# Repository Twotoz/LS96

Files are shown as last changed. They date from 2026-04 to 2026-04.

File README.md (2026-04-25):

# 1S 2-Inch High-KV Toothpick FPV Quad

A custom ultra-light **1S 2-inch toothpick FPV quad** designed around a specific idea:

> **Use a small, high-KV 2-inch powertrain for extreme responsiveness and punch, but place it on a larger 96 mm frame to gain stability, grip, protection, and a more locked-in flight feel.**



This is not a normal compact 2-inch toothpick, and it is not trying to become a slow, floaty 3-inch cruiser.

It is designed to sit between both concepts:

- **2-inch response**
- **high-KV punch**
- **low prop inertia**
- **larger-frame stability**
- **better component protection**
- **very low AUW**
- **extreme 1S thrust-to-weight**

In short:

> **A 1S 2-inch toothpick with 5-inch attitude.**

---

## Core Concept

Most 2-inch toothpick frames are around **85 mm motor-to-motor**. They are compact, light, and responsive, but can also feel twitchy and nervous at speed.

This frame uses a larger **96 mm wheelbase**, while still staying extremely light. The larger wheelbase gives the quad more mechanical leverage, more stability, better component protection, and a less twitchy feel.

At the same time, the quad still uses:

- high-KV 1002 motors
- 2-inch lightweight bi-blade props
- very low prop inertia
- low AUW
- 1S power

This keeps the quad extremely responsive and punchy.

The design goal is:

```text
2-inch responsiveness
+
high-KV punch
+
96 mm locked-in frame feel
=
responsive, stable, aggressive 1S micro quad
```

---

## Main Specs

| Item | Specification |
|---|---:|
| Class | 1S 2-inch toothpick |
| Frame wheelbase | 96 mm |
| Typical 2-inch frame reference | ~85 mm |
| Frame material | Carbon fiber |
| Frame thickness | 2 mm |
| Frame area | ~1258 mm² |
| Estimated frame weight | ~3.8–4.0 g |
| Motors | 1002 high-KV brushless |
| Planned KV | 25000KV |
| Alternative KV | 22000KV |
| Motor weight | ~2.5 g each including wires |
| Props | Gemfan GF2015 bi-blade |
| Prop size | 2.0 inch |
| Experimental prop size | 2.2 inch low pitch |
| Battery | 1S LiHV, LAVA 580 mAh |
| Estimated dry weight | ~25–26 g |
| Estimated AUW | ~39–40 g |
| Estimated thrust | ~400–412 g total |
| Estimated thrust-to-weight | ~10:1 |

---

## Estimated Weight Breakdown

| Component | Estimated Weight |
|---|---:|
| 2 mm carbon frame | ~3.8–4.0 g |
| 4x 1002 motors, including wires | ~10.0 g |
| Canopy | ~0.55 g |
| Camera | ~1.5 g |
| FC AIO | ~4.0 g |
| Battery connector + wires | ~2.0 g |
| 4x Gemfan GF2015 bi-blade props | ~2.0 g |
| 12x M1.4 motor screws | ~0.5–0.8 g |
| 4x FC rubber grommets | ~0.2–0.4 g |
| 4x M2 FC screws | ~0.4–0.8 g |
| 4x 3D printed motor dampers | ~0.1 g |
| 3D printed FC protector | ~0.2 g |

Estimated dry weight without battery:

```text
~25–26 g
```

With a LAVA 1S 580 mAh LiHV battery:

```text
~39–40 g AUW
```

---

## Frame Weight Estimate

The final frame area is approximately:

```text
1258 mm²
```

Frame thickness:

```text
2 mm
```

Volume:

```text
1258 mm² × 2 mm = 2516 mm³
```

Convert to cubic centimeters:

```text
2516 mm³ = 2.516 cm³
```

Using a typical carbon fiber composite density of roughly **1.5–1.6 g/cm³**:

```text
2.516 cm³ × 1.5 g/cm³ = 3.77 g
2.516 cm³ × 1.6 g/cm³ = 4.03 g
```

Estimated frame weight:

```text
~3.8–4.0 g
```

This is extremely light for a 96 mm frame that can support larger-than-normal 2-inch prop options.

---

## Why a 96 mm Frame?

Most normal 2-inch toothpick frames are around **85 mm**. This frame is larger at **96 mm**, which gives several advantages.


### 1. More Control Authority

A quad controls roll and pitch by creating thrust differences between motors. The motors act at a distance from the center of gravity.

The basic relationship is:

```text
torque = force × arm length
```

Or, for a quad:

```text
roll/pitch torque = thrust difference × motor distance from center
```

Compared to an 85 mm frame:

```text
96 / 85 = 1.129
```

This means the 96 mm frame gives about:

```text
~13% more motor leverage
```

So for the same thrust difference, the motors have more mechanical advantage for roll and pitch corrections.

In practice, this should make the quad feel:

- more controlled
- more locked-in
- less nervous
- better at correcting attitude
- more stable during fast direction changes

---

### 2. Less Twitchy Flight Feel

Very small 2-inch frames can feel extremely sharp, but also twitchy. The motors are close to the center, and the quad has low rotational inertia.

A slightly larger frame increases the rotational inertia of the quad. That means the quad resists unwanted angular changes a bit more.

The basic relationship is:

```text
angular acceleration = torque / moment of inertia
```

Or:

```text
α = τ / I
```

A higher moment of inertia makes the quad less twitchy and more predictable.

This does **not** mean the quad becomes slow, because the powertrain still uses small 2-inch props and high-KV motors. The frame calms the body down, while the motors and props keep the response fast.

The result should be:

```text
less twitchy than a normal 2-inch
but still much more responsive than a 3-inch
```

---

### 3. Better Component Protection

The longer arms help protect the important electronics.

Because the motors and arms sit farther away from the center stack, the frame creates a larger physical protection zone around:

- FC
- camera
- canopy
- wiring
- battery connector
- battery area

In crashes, the arms and motor area are more likely to take the first impact instead of the electronics.

This is especially useful on a very light quad, because the frame acts like a protective perimeter around the sensitive parts.

---

### 4. More Prop Clearance

The larger frame allows more prop flexibility than a normal compact 2-inch frame.

Supported / possible prop sizes:

| Prop Size | Status |
|---|---|
| 2.0 inch | Recommended |
| 2.2 inch low pitch | Good experimental option |
| 2.4 inch | Possible, but KV-dependent |
| 2.5 inch | Experimental, KV-dependent |

The frame is designed to physically allow larger prop options, but the main build philosophy is still focused on keeping prop inertia low.

---

## Design Philosophy

The design is based on a clear trade-off:

```text
Do not use the largest prop possible.
Use the largest useful performance while keeping response extremely fast.
```

Large props can give more efficiency, more glide, and more float, but they also have more rotational inertia.

More prop inertia means:

- slower spool-up
- slower spool-down
- less immediate throttle response
- more motor load
- more voltage sag
- more heat
- less direct stick feel

This quad avoids the slow prop-spool feeling that can happen on larger 1S 3-inch builds.

Instead, the preferred setup is:

```text
high-KV 1002 motors
+
lightweight 2-inch bi-blade props
+
larger 96 mm frame
```

This gives:

- fast prop response
- high RPM
- strong punch
- low prop inertia
- stable frame geometry
- locked-in feel
- less twitchy behavior

In short:

```text
Small prop for response.
High KV for punch.
Large frame for stability.
```

---

## 1002 Motor Theory

The motor size used in this build is **1002**.

This means approximately:

```text
10 mm stator diameter
2 mm stator height
```

A 1002 motor is very small and light. The benefits are:

- low motor weight
- low rotor inertia
- fast throttle response
- fast RPM changes
- very direct feel
- excellent for ultralight 1S builds

The downsides are:

- limited torque
- limited thermal mass
- limited continuous power
- high current draw at high KV
- easy to overload with large props

A 1002 motor is not meant to spin large 3-inch props aggressively. It is best suited for small, lightweight props where response matters more than cruise efficiency.

---

## 1S Electrical Theory

This build uses a **1S battery**, so voltage is limited.

Typical voltage:

```text
Nominal 1S LiPo: 3.7 V
Full 1S LiHV: 4.35 V
```

Motor no-load RPM is roughly:

```text
RPM = KV × voltage
```

For **25000KV**:

```text
25000 × 3.7 V = 92,500 RPM no-load
25000 × 4.35 V = 108,750 RPM no-load
```

For **22000KV**:

```text
22000 × 3.7 V = 81,400 RPM no-load
22000 × 4.35 V = 95,700 RPM no-load
```

These are no-load values. With a prop attached, real loaded RPM is much lower because of:

- prop load
- voltage sag
- motor torque limits
- battery current limit
- ESC losses
- aerodynamic drag

Realistic loaded RPM for the 25000KV 2-inch setup is expected to be around:

```text
~45,000–60,000 RPM
```

This is still extremely high for a micro quad and is one of the reasons the build should feel very aggressive.

---

## Prop Load Theory

Propeller load increases very quickly with diameter.

A simplified rule is:

```text
prop power demand ∝ diameter^4 to diameter^5 × RPM^3
```

This means a small increase in prop diameter can create a much larger increase in motor load.

Using 2.0 inch as a baseline:

| Prop Size | Diameter Ratio | Load Estimate Using D⁴ | Load Estimate Using D⁵ |
|---:|---:|---:|---:|
| 2.0" | 1.00x | 1.00x | 1.00x |
| 2.2" | 1.10x | 1.46x | 1.61x |
| 2.4" | 1.20x | 2.07x | 2.49x |
| 2.5" | 1.25x | 2.44x | 3.05x |
| 3.0" | 1.50x | 5.06x | 7.59x |

This explains why 2.4–2.5 inch props can become questionable on 25000KV 1002 motors.

Even if the prop physically fits, it may not make sense electrically or dynamically.

---

## Prop Inertia Theory

Responsiveness depends heavily on prop inertia.

The motor has to accelerate and decelerate the prop. For rotation:

```text
angular acceleration = motor torque / rotational inertia
```

Or:

```text
α = τ / I
```

A prop with lower rotational inertia can change RPM faster.

Prop inertia roughly depends on:

```text
I ≈ m × r²
```

Where:

- `m` = prop mass
- `r` = prop radius

A larger prop has more radius and usually more mass, so inertia increases quickly.

Compared to a 2-inch prop, a 3-inch prop has:

```text
3 / 2 = 1.5x diameter
```

Radius effect alone:

```text
1.5² = 2.25x inertia
```

But because the 3-inch prop is also heavier, real inertia can be several times higher.

That is why a 3-inch 1S quad often feels more floaty and less immediate.

This build avoids that by using small, lightweight bi-blade props.

---

## Why Bi-Blade Props?

Bi-blade props are preferred for this build.

Compared to tri-blades, bi-blades usually have:

- lower weight
- lower rotational inertia
- faster spool-up
- faster spool-down
- lower current draw
- better efficiency
- less voltage sag
- less motor heat
- longer flight time

On a high-KV 1S build, this matters a lot.

The motors are already spinning very fast and drawing high current. A heavier tri-blade would increase the load, reduce efficiency, create more sag, and make the motors run hotter.

The preferred prop style is:

```text
lightweight low-pitch bi-blade
```

Recommended options:

| Prop Type | Recommendation |
|---|---|
| 2.0" bi-blade | Best match |
| 2.2" low-pitch bi-blade | Good experimental option |
| 2.4" bi-blade | Better suited for lower KV |
| 2.5" bi-blade | Experimental, lower KV preferred |
| Tri-blade | Not preferred |

---

## GF2015 Prop Setup

The main prop choice is:

```text
Gemfan GF2015 bi-blade
```

This is a:

```text
2.0 inch diameter
1.5 pitch
2-blade prop
```

This prop fits the design goal well:

- low mass
- low inertia
- fast spool
- good thrust
- good efficiency
- high RPM capable
- suitable for aggressive 1S setups

The GF2015 is the main recommended prop for the 25000KV setup.

---

## 22000KV vs 25000KV

Known/expected thrust on GF2015:

| Motor KV | Thrust Per Motor | Total Thrust |
|---:|---:|---:|
| 22000KV | ~93 g | ~372 g |
| 25000KV | ~103 g | ~412 g |

Difference per motor:

```text
103 g - 93 g = 10 g
```

Difference total:

```text
10 g × 4 motors = 40 g
```

Relative difference:

```text
103 / 93 = 1.108
```

So 25000KV gives about:

```text
~11% more thrust
```

The trade-off is that 25000KV will likely have:

- higher current draw
- more voltage sag
- more heat
- shorter flight time
- more aggressive throttle response

The 22000KV version is still extremely strong, but easier on the battery and electronics.

---

## Thrust-to-Weight

Estimated AUW:

```text
~39–40 g
```

With 25000KV motors on GF2015:

```text
~103 g thrust per motor
```

Total thrust:

```text
103 g × 4 = 412 g
```

Thrust-to-weight:

```text
412 g / 40 g = 10.3:1
```

With 22000KV motors on GF2015:

```text
93 g × 4 = 372 g
```

Thrust-to-weight:

```text
372 g / 40 g = 9.3:1
```

Estimated thrust-to-weight comparison:

| Setup | Total Thrust | AUW | T/W |
|---|---:|---:|---:|
| 22000KV + GF2015 | ~372 g | ~40 g | ~9.3:1 |
| 25000KV + GF2015 | ~412 g | ~40 g | ~10.3:1 |

Both are extremely powerful for a 1S micro quad.

---

## Current Draw

The 25000KV setup can draw around:

```text
~12 A per motor
```

Total current at full throttle:

```text
12 A × 4 = 48 A
```

This is a lot for a 1S battery.

The LAVA 1S 580 mAh battery is a high-discharge pack, but full throttle is still a very heavy load for a single cell.

Expected behavior:

- short punch-outs should be possible
- long full-throttle runs are not recommended
- voltage sag is expected
- motor temperature should be checked
- ESC temperature should be checked
- battery temperature should be checked
- connector and wire temperature should be checked

Because the quad has such a high thrust-to-weight ratio, full throttle should rarely be needed.

This is important:

```text
The quad has more power than it usually needs.
The battery only sees peak load during short bursts.
```

---

## Prop Size Compatibility

The frame can physically support props larger than 2 inches, but the motor and KV choice determine what actually makes sense.

### Recommended Prop Sizes

| Motor KV | Prop Size | Recommendation |
|---:|---|---|
| 25000KV | 2.0" bi-blade | Ideal |
| 25000KV | 2.2" low-pitch bi-blade | Good experimental option |
| 25000KV | 2.4" bi-blade | Borderline / risky |
| 25000KV | 2.5" bi-blade | Not recommended |
| 22000KV | 2.0" bi-blade | Safe |
| 22000KV | 2.2" bi-blade | Good |
| 22000KV | 2.4" bi-blade | Testable |
| 22000KV | 2.5" bi-blade | Experimental |
| 1002 any KV | 3.0" | Not recommended for this concept |

---

## Why Not 3-Inch?

A 3-inch 1S build can be efficient, floaty, and smooth, but that is not the goal of this quad.

A 3-inch prop has much higher inertia and much higher load. It will not spool as quickly as a 2-inch prop.

The result is often:

- more glide
- more float
- better cruise efficiency
- slower response
- more lazy throttle feel
- less sharp stick response

This build is designed to avoid that.

The goal is not maximum prop size.

The goal is:

```text
maximum useful thrust
with minimum prop inertia
and maximum response
```

This is why the frame may physically support larger props, but the recommended setup stays around 2.0–2.2 inches.

---

## Comparison: This Build vs 1S 3-Inch 1202.5

A 1S 3-inch 1202.5 build usually uses:

- larger motors
- larger props
- lower KV
- more prop disc area
- more glide
- more efficiency at cruise
- more floaty flight feel

This build uses:

- smaller motors
- higher KV
- smaller props
- lower prop inertia
- lower AUW
- faster response
- more punch per gram

Comparison:

| Characteristic | This 2" 1002 Build | 1S 3" 1202.5 Build |
|---|---|---|
| Prop response | Very fast | Slower |
| Prop inertia | Low | Higher |
| Punch feel | Very aggressive | Strong but softer |
| Glide | Lower | Higher |
| Cruise efficiency | Good, but not main goal | Better |
| Stick feel | Sharp/direct | Smoother/floatier |
| AUW | ~39–40 g | Often ~50–60 g |
| Frame feel | Locked-in but responsive | Stable and floaty |
| Main goal | Response and punch | Efficiency and glide |

The 3-inch build may be better for relaxed cruising and longer flight time.

This 2-inch build should be better for:

- fast reaction
- punch-outs
- tight control
- quick direction changes
- aggressive flying
- low prop-spool delay

---

## Expected Flight Feel

The expected flight feel is:

```text
sharp
responsive
punchy
locked-in
less twitchy than a normal 2-inch
more aggressive than a 3-inch 1S cruiser
```

Expected characteristics:

- very fast throttle response
- minimal prop spool delay
- strong punch-outs
- high-pitched motor sound
- very low mass
- fast direction changes
- less twitchy than compact 2-inch frames
- more stable than typical 85 mm 2-inch frames
- less float than 3-inch 1S
- very high thrust-to-weight
- high current peaks

---

## Expected Sound

Because of the high KV and high RPM, this quad should have a very high-pitched sound.

It will not sound exactly like a 5-inch, because a 5-inch prop moves much more air and has a deeper sound.

However, the high RPM and fast spool should give this quad an aggressive micro scream.

Expected sound:

```text
high-pitched
sharp
angry
fast spool-up
mini race-drone character
```

---

## Estimated Speed

A realistic top speed estimate is:

```text
~90–120 km/h
```

Higher peaks may be possible with:

- fresh LiHV battery
- good tune
- low drag build
- full throttle burst
- favorable wind
- clean prop condition

But top speed is not the main design goal.

The main design goals are:

- response
- punch
- control
- locked-in feel
- low AUW

---

## Motor Dampers

The build uses four custom 3D printed motor dampers.

Per damper:

```text
Area: 44 mm²
Thickness: 0.5 mm
```

Volume per damper:

```text
44 mm² × 0.5 mm = 22 mm³
```

For four dampers:

```text
22 mm³ × 4 = 88 mm³
```

Convert to cubic centimeters:

```text
88 mm³ = 0.088 cm³
```

With typical 3D print material density around 1.2 g/cm³:

```text
0.088 cm³ × 1.2 g/cm³ = 0.106 g
```

Estimated total weight:

```text
~0.1 g
```

The motor dampers add almost no weight, but may help isolate vibration between the motors and frame.

---

## FC Protector

The final FC protector area is:

```text
347 mm²
```

Assuming 0.5 mm thickness:

```text
347 mm² × 0.5 mm = 173.5 mm³
```

Convert to cubic centimeters:

```text
173.5 mm³ = 0.1735 cm³
```

With 3D printed material around 1.2–1.27 g/cm³:

```text
~0.21–0.22 g
```

Estimated FC protector weight:

```text
~0.2 g
```

This is a very small weight penalty for extra protection.

---

## Battery

Planned battery:

```text
BETAFPV LAVA 1S 580 mAh LiHV
```

Estimated battery weight:

```text
~14.1 g
```

Estimated AUW with this battery:

```text
dry weight ~25–26 g
battery ~14.1 g
total ~39–40 g
```

---

## Strengths

This build should be strong in:

- throttle response
- punch
- fast RPM changes
- low prop-spool delay
- low AUW
- high thrust-to-weight
- control authority
- locked-in frame feel
- component protection
- aggressive 1S performance

---

## Trade-Offs

The design is not optimized for maximum flight time or smooth cruising.

Expected trade-offs:

- high current draw
- voltage sag during hard punch-outs
- motor heat if over-propped
- battery stress at full throttle
- less glide than 3-inch
- less cruise efficiency than larger prop setups
- tune may need care because of high power and low mass

This is a performance-focused 1S build, not a relaxed cruiser.

---

## Recommended Testing Procedure

When testing new props or motor KV combinations:

1. Start with short hover tests.
2. Check motor temperature after 20–30 seconds.
3. Check battery temperature.
4. Check ESC temperature.
5. Do short punch-outs only.
6. Watch voltage sag.
7. Avoid long full-throttle runs at first.
8. Review blackbox if available.
9. Increase throttle load gradually.
10. Stop testing if motors become too hot to touch.

Recommended first setup:

```text
1002 25000KV
GF2015 bi-blade
1S LiHV
throttle limit optional
```

Optional safer initial Betaflight setup:

```text
Throttle limit: 85–90%
```

This can reduce current spikes while still keeping the quad very fast.

---

## Recommended Build Direction

Best match for the design goal:

```text
1002 25000KV
GF2015 2-inch bi-blade
1S LAVA 580 mAh
96 mm carbon frame
~40 g AUW
```

This gives the most aggressive version of the concept.

More efficient / safer version:

```text
1002 22000KV
GF2015 or 2.2-inch low-pitch bi-blade
1S LAVA 580 mAh
96 mm carbon frame
~40 g AUW
```

Experimental larger-prop version:

```text
1002 22000KV
2.4-inch bi-blade
careful temperature testing required
```

Not recommended for the main goal:

```text
25000KV + 2.5-inch
1002 + 3-inch
heavy tri-blades
long full-throttle runs
```

---

## Final Summary

This quad is designed around a very specific theory:

```text
Use the smallest prop that can still make serious thrust.
Use high KV to create punch and RPM.
Use low prop inertia to keep response instant.
Use a larger frame to make the quad less twitchy and more locked-in.
Keep the whole build extremely light.
```

The result should be a 1S quad that feels:

- much more responsive than a 3-inch 1S build
- less twitchy than a compact 2-inch build
- more locked-in than a normal toothpick
- extremely punchy for its size
- very light
- very aggressive
- very fun

In one sentence:

> **A 96 mm 1S 2-inch high-KV toothpick designed for instant response, extreme punch, and a larger-quad locked-in feel without the lazy spool of bigger props.**



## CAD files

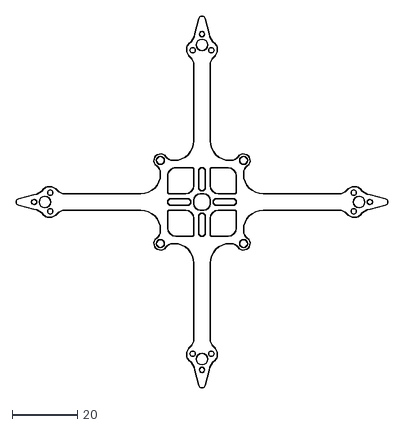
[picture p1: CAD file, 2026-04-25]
dxf/LS96 V1.0.2.dxf
113.6 x 113.6

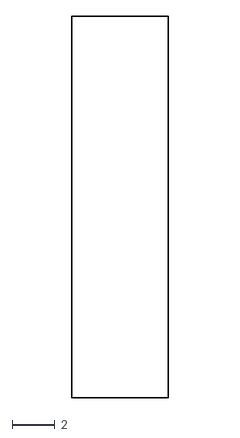
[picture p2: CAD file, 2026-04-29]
stl/SL96 V1.0.3 Battery Holder 580lava.dxf
4.52 x 17.9

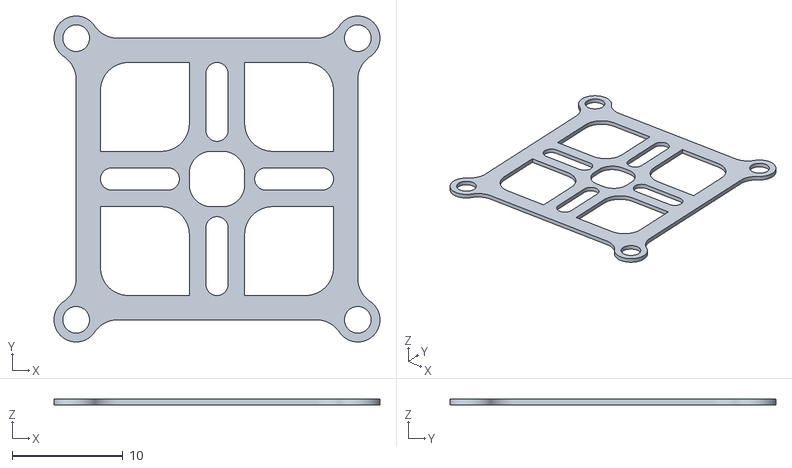
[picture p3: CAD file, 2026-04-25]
stl/SL96 V1.0.1 FC Protector.stl
29.4 x 29.4 x 0.5

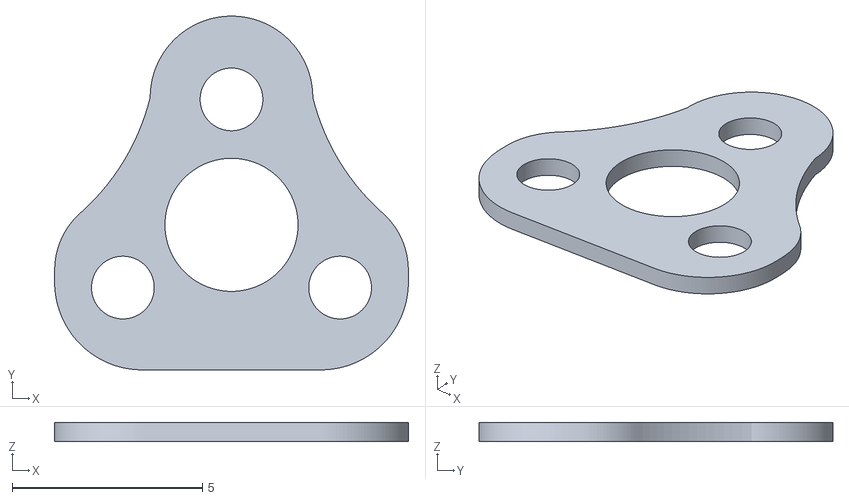
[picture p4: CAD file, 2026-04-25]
stl/SL96 V1.0.1 Motor Damper.stl
9.31 x 9.31 x 0.5

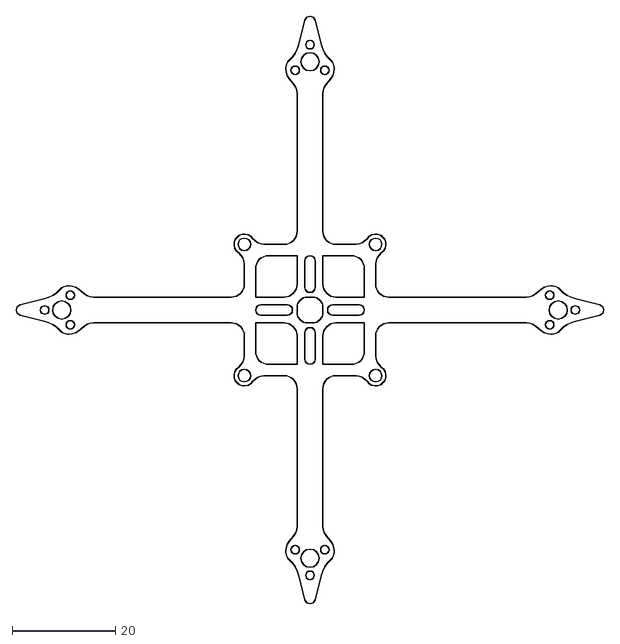
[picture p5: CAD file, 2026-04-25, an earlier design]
dxf/LS96 v1.0.1.dxf
113.6 x 113.6

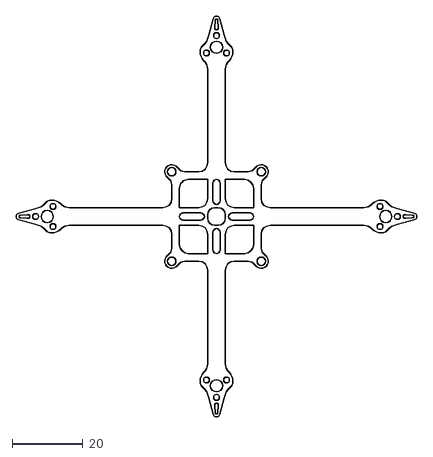
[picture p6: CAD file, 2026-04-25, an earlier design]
dxf/LS96 v1.0.0.dxf
113.6 x 113.6

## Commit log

2026-04-25 added bom.md
2026-04-25 Add image to README for 96 mm frame advantages
2026-04-25 added v1.0.2 battery holder
2026-04-29 added v1.0.3 bat holder
    [SL96 V1.0.3 Battery Holder 580lava.dxf]
